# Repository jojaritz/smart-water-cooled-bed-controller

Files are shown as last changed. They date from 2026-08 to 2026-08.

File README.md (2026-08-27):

# smart-water-cooled-bed-controller
An open-source, IoT-enabled fluid thermal management system engineered to actively regulate mattress sleep temperatures. Powered by an ESP32 microcontroller, dual isolated liquid loops, a custom high-power KiCad PCB handling up to 18A continuous current, and a local responsive Web dashboard.

---

## System Overview & Architecture

The system uses a 4-module parallel thermoelectric (Peltier) array to chill a continuous fluid loop running through tubing a mattress topper. A seperate, high-flow exhaust loop pulls waste heat into a 360mm radiator to maintain thermal efficiency without acoustic disruption.

```text
                                 [ 12V 29A Mean Well SMPS ]
                                              │
                    ┌─────────────────────────┴─────────────────────────┐
                    ▼                                                   ▼
       [ 12V-to-5V Buck Converter ]                       [ 4x 7.5A Fused Power Rails ]
                    │                                                   │
                    ▼                                                   ▼
           [ ESP32 Controller ] ──(3.3V Logic)──► [ 4x IRLZ44N N-Channel MOSFETs ]
             │              │                                           │
 (25 kHz PWM)│              └──(1-Wire Bus)──┐                          ▼
             ▼                               ▼                  [ 4x Peltier Modules ]
   [ 2x DDC Fluid Pumps ]          [ 2x DS18B20 Probes ]          (Cooling Engine)
             │                               │                          │
             ▼                               ▼                          ▼
   [ Dual Fluid Circuits ] ◄─────────────────┴──────────────────────────┘
```

## Technical Specifications

| Specification | Implementation | 
| :--- | :--- |
| **Microcontroller** | ESP32-WROOM-32 (240 MHz Dual-Core, 2.4 GHz SoftAP) |
| **Power Supply Unit** | Mean Well LRS-340-12 (12V DC, 29A, 348W continuous) |
| **Cooling Engine** | 4x Parallel Thermoelectric Modules (TEC1-12706 / CP Series) |
| **Current Handling** | 18.0A continuous load across 4 distributed 7.5 A fused sub-channels |
| **Switching Architecture** | Low-Side N-channel Logic MOSFETs (IRLZ44N) with 10kΩ gate anchors |
| **Temperature Telemetry** | Dual Dallas 1-wire DS18B20 waterproof probes (4.7kΩ pull-up) |
| **Fluid Management** | Dual isolated DDC PWM pumps + 360mm copper-core radiator |
| **Control Logic** | Non-blocking ±0.5°C hysteresis with 55°C hot-loop thermal runaway trip |

---

## Custom Hardware & PCB Engineering (KiCad)

The power management shield was designed in **KiCad** to solve high-current thermal stress and signal isolation:

* **Distributed Power Architecture:** Instead of routing 18A through a single trace , the board splits current into 4 - 4.5A branches (2 copper traces each) protected by individual 7.5A ATO blade fuses.
* **Trace Sizing (IPC-2221):** Power traces are routed at 3.5mm width on 1oz copper with teardrops on high-stress terminal pads to eliminate delamination risks.
* **Unified Ground Plane:** A full-coverage bottom-layer copper pour ties the 12V DC ground and 5V ESP32 reference together, eliminating gate-switching floating transients.
* **Gate Protection:** Features a 10kΩ pull-down resistor to prevent floating gates during bootup, plus individual 150Ω gate resistors on each MOSFET to eliminate ringing reflections.

---

## Firmware & Software Architecture

The firmware is written in C++ for the ESP32 platform:

* **Embedded SoftAP Web Dashboard:** Hosts a zero-dependency HTML/CSS/JavaScript control dashboard served directly from flash memory. No internet connection or cloud service is required.
* **Hysteresis Temperature Loop:** Enforces a ±0.5°C switching window to prevent short-cycling the MOSFETs and damaging the Peltier ceramic layers.
* **Hardware Watchdog Interlocks:**
  * Auto-shuts off the MOSFETs if the hot-loop sensor exceeds **55.0°C**.
  * Emergency stops if a 1-Wire sensor disconnects (reading `-127.0°C` or `85.0°C`).

---

## Key Engineering Decisions & Trade-Offs

1. **Parallel Array vs. Cascaded (Stacked) Modules:**
   * *Trade-off:* Stacking modules increases temperature difference ($\Delta T$) but drastically chokes heat capacity ($Q_c$) because the outer Peltier must absorb the inner unit's electrical waste heat.
   * *Decision:* Used a 4-module parallel array to maximize continuous wattage removal from the bed loop.
2. **Dual Isolated Fluid Loops:**
   * *Trade-off:* Requires two pumps and separate plumbing lines.
   * *Decision:* Prevents mixing chilled bed fluid with high-temperature radiator exhaust fluid, maximizing heat dissipation.
3. **All-Aluminum Metallurgy & Closed-Cell Insulation:**
   * *Decision:* Standardized on aluminum water blocks and fittings to prevent galvanic corrosion, and insulated cold lines with neoprene to eliminate condensation on internal electronics.

---

## Hardware Bring-Up & Validation Protocol

The physical system was brought up following a 5-phase staged protocol:

1. **Cold Continuity Verification:** Multimeter checks for shorts across 12V and GND screw terminals.
2. **Buck Calibration:** Regulated onboard converter output to **5.00V DC** before inserting the ESP32.
3. **Gate Switching Verification:** Validated 0.0V (OFF) and 3.3V (ON) logic levels on MOSFET gates.
4. **24-Hour Hydrodynamic Leak Test:** Fluid loops pressurized and circulated with electronics isolated.
5. **Full-Load Thermal Soak:** Validated 18A continuous draw under full cooling engagement.

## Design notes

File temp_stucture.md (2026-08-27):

#Test

```text

smart-water-cooled-bed-controller/
├── .gitignore
├── LICENSE
├── README.md
├── cad/
│   └── (Exported STL & STEP 3D-printable mount files)
├── docs/
│   └── (System diagrams, pinout charts, and test screenshots)
├── firmware/
│   └── src/
│       └── main.cpp
└── hardware/
    ├── bom/
    │   └── BOM.csv
    ├── gerbers/
    │   └── (Fabrication drill and layer ZIP export)
    └── schematics/
        └── schematic.pdf

```

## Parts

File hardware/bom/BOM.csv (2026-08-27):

Item | Designator | Component Description | Qty | Footprint / Form Factor | Sourcing Reference
1 | U1 | ESP32-WROOM-32 Development Board | 1 | 2x19 2.54mm Pin Header Socket | Espressif
2 | U2 | MP1584 / LM2596 DC-DC Buck Converter (12V to 5V) | 1 | 4-Pin Through-Hole Module | Generic / Amazon
3 | Q1-Q4 | IRLZ44N Logic-Level N-Channel MOSFET | 4 | TO-220 | Infineon / Vishay
4 | TEC1-TEC4 | TEC1-12706 / High-Density Peltier Module | 4 | 40mm x 40mm Solid-State | CUI / Generic
5 | F1-F4 | 7.5A Mini Blade Fuse + PCB Fuse Clips | 4 | Automotive Blade Holder | Littelfuse
6 | R1 | 4.7kΩ Resistor (1/4W 5%) | 1 | Axial P10.16mm | 1-Wire Pull-Up
7 | R2 | 10kΩ Resistor (1/4W 5%) | 1 | Axial P10.16mm | Gate Pull-Down
8 | R3-R6 | 150Ω Resistor (1/4W 5%) | 4 | Axial P10.16mm | Gate Ringing Suppression
9 | TB1-TB8 | 2-Pin 5.08mm PCB Screw Terminal Blocks | 8 | MKDS 1.5/2-5.08 | Phoenix Contact
10 | J1-J3 | 4-Pin 2.54mm Male PWM Headers | 3 | Vertical 1x04 Pin Header | Molex / Generic
11 | SEN1-SEN2 | DS18B20 Waterproof Temperature Sensor Probe | 2 | Dallas 1-Wire Probe | Maxim Integrated
12 | PSU | Mean Well LRS-350-12 (12V 29A 348W SMPS) | 1 | Industrial Enclosure | Mean Well
13 | PUMP1-PUMP2 | Freezemod DDC-Style 12V PWM Water Pump + Reservoir | 2 | PC Water Cooling Fitting | Freezemod
14 | RAD | 360mm Aluminum Heat Exchanger Radiator + 3x 120mm Fans | 1 | Standard PC Liquid Cooling | Generic

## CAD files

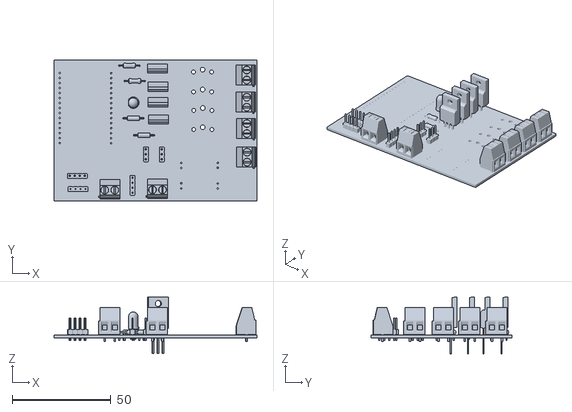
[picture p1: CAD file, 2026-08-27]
cad/mattress_cooler_powercontroller.stl
103.0 x 71.4 x 28.9

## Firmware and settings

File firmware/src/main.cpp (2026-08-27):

#include <WiFi.h>
#include <WebServer.h>
#include <OneWire.h>
#include <DallasTemperature.h>

// ==================== PIN DEFINITIONS ====================
#define ONE_WIRE_BUS      22  // GPIO 22: DS18B20 1-Wire Data Bus
#define MOSFET_GATE_PIN   23  // GPIO 23: MOSFET Gate Control Line
#define HOT_PUMP_PWM_PIN  21  // GPIO 21: Hot Exhaust Loop Pump PWM
#define COLD_PUMP_PWM_PIN 18  // GPIO 18: Cold Bed Loop Pump PWM

// ==================== WI-FI AP CREDENTIALS ====================
const char* apSSID = "WaterBed-Controller";
const char* apPASS = "coolingsystem"; // Minimum 8 characters

// ==================== SYSTEM & THERMAL SETTINGS ====================
float targetBedTemp    = 20.0;  // Target Cold Loop Temperature (°C)
float hysteresis       = 0.5;   // +/- 0.5°C Hysteresis Window
float maxHotLoopTemp   = 55.0;  // Emergency Overheat Threshold (°C)

int hotPumpSpeedPercent  = 85;  // Default Radiator Pump Duty Cycle (%)
int coldPumpSpeedPercent = 60;  // Default Bed Pump Duty Cycle (%)

// ==================== GLOBAL OBJECTS & STATE ====================
OneWire oneWire(ONE_WIRE_BUS);
DallasTemperature sensors(&oneWire);
WebServer server(80);

const int pwmFreq = 25000; // 25 kHz PC Fan Standard
const int pwmRes  = 8;     // 8-bit (0-255)

float currentColdTemp = 25.0;
float currentHotTemp  = 25.0;
bool isCoolingActive   = false;
bool emergencyShutdown = false;
int deviceCount = 0;

const unsigned long SENSOR_INTERVAL = 1500;
unsigned long lastSensorReadTime    = 0;

// ==================== EMBEDDED DASHBOARD HTML ====================
const char INDEX_HTML[] PROGMEM = R"rawliteral(
<!DOCTYPE html>
<html lang="en">
<head>
  <meta charset="UTF-8">
  <meta name="viewport" content="width=device-width, initial-scale=1.0">
  <title>Smart Bed Thermal Hub</title>
  <style>
    :root { --bg: #0f172a; --card: #1e293b; --accent: #38bdf8; --text: #f8fafc; --warn: #ef4444; --green: #22c55e; }
    body { font-family: -apple-system, BlinkMacSystemFont, "Segoe UI", Roboto, sans-serif; background: var(--bg); color: var(--text); margin: 0; padding: 16px; display: flex; justify-content: center; }
    .container { width: 100%; max-width: 480px; }
    h1 { font-size: 1.4rem; text-align: center; margin-bottom: 20px; color: var(--accent); }
    .grid { display: grid; grid-template-columns: 1fr 1fr; gap: 12px; margin-bottom: 12px; }
    .card { background: var(--card); border-radius: 12px; padding: 16px; text-align: center; box-shadow: 0 4px 6px -1px rgba(0,0,0,0.3); }
    .card.full { grid-column: span 2; }
    .label { font-size: 0.8rem; text-transform: uppercase; color: #94a3b8; margin-bottom: 6px; }
    .val { font-size: 2rem; font-weight: bold; color: var(--text); }
    .unit { font-size: 1rem; color: #94a3b8; }
    .badge { display: inline-block; padding: 4px 12px; border-radius: 9999px; font-weight: 600; font-size: 0.85rem; }
    .badge.on { background: rgba(34, 197, 94, 0.2); color: var(--green); border: 1px solid var(--green); }
    .badge.off { background: rgba(148, 163, 184, 0.2); color: #94a3b8; }
    .badge.trip { background: rgba(239, 68, 68, 0.2); color: var(--warn); border: 1px solid var(--warn); }
    .controls { display: flex; align-items: center; justify-content: space-between; gap: 12px; margin-top: 10px; }
    .btn { background: var(--accent); color: #0f172a; border: none; border-radius: 8px; font-size: 1.5rem; font-weight: bold; width: 48px; height: 48px; cursor: pointer; }
    .slider-row { margin-top: 10px; text-align: left; }
    .slider-row label { display: flex; justify-content: space-between; font-size: 0.85rem; color: #94a3b8; }
    input[type=range] { width: 100%; accent-color: var(--accent); margin-top: 6px; }
  </style>
</head>
<body>
  <div class="container">
    <h1>Smart Bed Thermal Hub</h1>
    <div class="grid">
      <div class="card">
        <div class="label">Cold Loop (Bed)</div>
        <div class="val" id="coldTemp">--<span class="unit">°C</span></div>
      </div>
      <div class="card">
        <div class="label">Hot Loop (Radiator)</div>
        <div class="val" id="hotTemp">--<span class="unit">°C</span></div>
      </div>
      <div class="card full">
        <div class="label">Peltier State</div>
        <div id="peltierBadge" class="badge off">STANDBY</div>
      </div>
      <div class="card full">
        <div class="label">Target Bed Temperature</div>
        <div class="controls">
          <button class="btn" onclick="adjustTarget(-0.5)">-</button>
          <div class="val"><span id="targetTemp">20.0</span><span class="unit">°C</span></div>
          <button class="btn" onclick="adjustTarget(0.5)">+</button>
        </div>
      </div>
      <div class="card full">
        <div class="label">Pump Flow Controls</div>
        <div class="slider-row">
          <label>Cold Pump Speed: <span id="coldPumpVal">60%</span></label>
          <input type="range" min="30" max="100" value="60" onchange="updatePumps()" id="coldSlider">
        </div>
        <div class="slider-row" style="margin-top:14px;">
          <label>Hot Pump Speed: <span id="hotPumpVal">85%</span></label>
          <input type="range" min="40" max="100" value="85" onchange="updatePumps()" id="hotSlider">
        </div>
      </div>
    </div>
  </div>
  <script>
    let currentTarget = 20.0;
    function fetchData() {
      fetch('/api/data')
        .then(res => res.json())
        .then(d => {
          document.getElementById('coldTemp').innerHTML = d.cold.toFixed(1) + '<span class="unit">°C</span>';
          document.getElementById('hotTemp').innerHTML = d.hot.toFixed(1) + '<span class="unit">°C</span>';
          document.getElementById('targetTemp').innerText = d.target.toFixed(1);
          currentTarget = d.target;
          const badge = document.getElementById('peltierBadge');
          if (d.emergency) {
            badge.className = 'badge trip';
            badge.innerText = 'OVERHEAT SAFETY TRIP';
          } else if (d.cooling) {
            badge.className = 'badge on';
            badge.innerText = 'COOLING ACTIVE (ON)';
          } else {
            badge.className = 'badge off';
            badge.innerText = 'STANDBY (OFF)';
          }
        });
    }
    function adjustTarget(delta) {
      currentTarget = Math.round((currentTarget + delta) * 10) / 10;
      fetch('/api/setTarget?val=' + currentTarget).then(() => fetchData());
    }
    function updatePumps() {
      const cold = document.getElementById('coldSlider').value;
      const hot = document.getElementById('hotSlider').value;
      document.getElementById('coldPumpVal').innerText = cold + '%';
      document.getElementById('hotPumpVal').innerText = hot + '%';
      fetch(`/api/setPumps?cold=${cold}&hot=${hot}`);
    }
    setInterval(fetchData, 1500);
    fetchData();
  </script>
</body>
</html>
)rawliteral";

// ==================== HELPER FUNCTIONS ====================
void applyPumpSpeeds() {
  uint8_t coldDuty = (uint8_t)((coldPumpSpeedPercent / 100.0) * 255.0);
  uint8_t hotDuty  = (uint8_t)((hotPumpSpeedPercent / 100.0) * 255.0);
  ledcWrite(COLD_PUMP_PWM_PIN, coldDuty);
  ledcWrite(HOT_PUMP_PWM_PIN, hotDuty);
}

void handleRoot() { server.send(200, "text/html", INDEX_HTML); }

void handleData() {
  String json = "{";
  json += "\"cold\":" + String(currentColdTemp, 2) + ",";
  json += "\"hot\":" + String(currentHotTemp, 2) + ",";
  json += "\"target\":" + String(targetBedTemp, 1) + ",";
  json += "\"cooling\":" + String(isCoolingActive ? "true" : "false") + ",";
  json += "\"emergency\":" + String(emergencyShutdown ? "true" : "false");
  json += "}";
  server.send(200, "application/json", json);
}

void handleSetTarget() {
  if (server.hasArg("val")) { targetBedTemp = server.arg("val").toFloat(); }
  server.send(200, "text/plain", "OK");
}

void handleSetPumps() {
  if (server.hasArg("cold")) coldPumpSpeedPercent = server.arg("cold").toInt();
  if (server.hasArg("hot"))  hotPumpSpeedPercent  = server.arg("hot").toInt();
  applyPumpSpeeds();
  server.send(200, "text/plain", "OK");
}

// ==================== SETUP ====================
void setup() {
  Serial.begin(115200);
  delay(500);

  pinMode(MOSFET_GATE_PIN, OUTPUT);
  digitalWrite(MOSFET_GATE_PIN, LOW);

  ledcAttach(HOT_PUMP_PWM_PIN, pwmFreq, pwmRes);
  ledcAttach(COLD_PUMP_PWM_PIN, pwmFreq, pwmRes);
  applyPumpSpeeds();

  sensors.begin();
  deviceCount = sensors.getDeviceCount();

  WiFi.softAP(apSSID, apPASS);
  Serial.println("\n[INFO] Access Point Started: http://192.168.4.1");

  server.on("/", handleRoot);
  server.on("/api/data", handleData);
  server.on("/api/setTarget", handleSetTarget);
  server.on("/api/setPumps", handleSetPumps);
  server.begin();
}

// ==================== MAIN LOOP ====================
void loop() {
  server.handleClient();

  unsigned long currentMillis = millis();
  if (currentMillis - lastSensorReadTime >= SENSOR_INTERVAL) {
    lastSensorReadTime = currentMillis;

    sensors.requestTemperatures();
    currentColdTemp = sensors.getTempCByIndex(0);
    currentHotTemp  = (deviceCount >= 2) ? sensors.getTempCByIndex(1) : 25.0;

    // 1. Sensor Disconnect Watchdog
    if (currentColdTemp == DEVICE_DISCONNECTED_C || currentColdTemp <= -100.0) {
      isCoolingActive = false;
      digitalWrite(MOSFET_GATE_PIN, LOW);
      return;
    }

    // 2. Overheat Emergency Interlock
    if (currentHotTemp >= maxHotLoopTemp) {
      emergencyShutdown = true;
      isCoolingActive = false;
      digitalWrite(MOSFET_GATE_PIN, LOW);
    } else if (emergencyShutdown && currentHotTemp < (maxHotLoopTemp - 5.0)) {
      emergencyShutdown = false;
    }

    // 3. Hysteresis Switching Engine
    if (!emergencyShutdown) {
      if (!isCoolingActive && currentColdTemp >= (targetBedTemp + hysteresis)) {
        isCoolingActive = true;
        digitalWrite(MOSFET_GATE_PIN, HIGH);
      } else if (isCoolingActive && currentColdTemp <= (targetBedTemp - hysteresis)) {
        isCoolingActive = false;
        digitalWrite(MOSFET_GATE_PIN, LOW);
      }
    }
  }
}

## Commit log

2026-08-27 Add BOM.csv with component details for hardware
    [BOM.csv]
2026-08-27 Add main firmware for smart bed thermal control
2026-08-27 3d model of water cooler powercontroller PCB
    [mattress_cooler_powercontroller.stl]
